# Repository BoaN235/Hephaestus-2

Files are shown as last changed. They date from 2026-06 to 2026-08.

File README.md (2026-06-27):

# Hephaestus-2

magazine_page

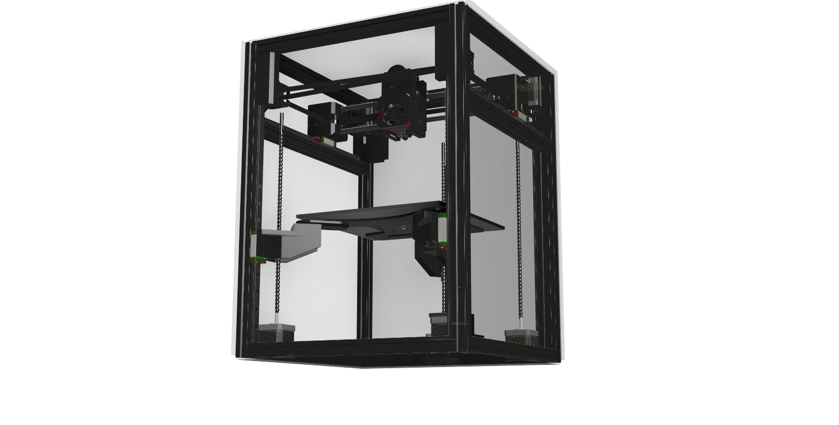
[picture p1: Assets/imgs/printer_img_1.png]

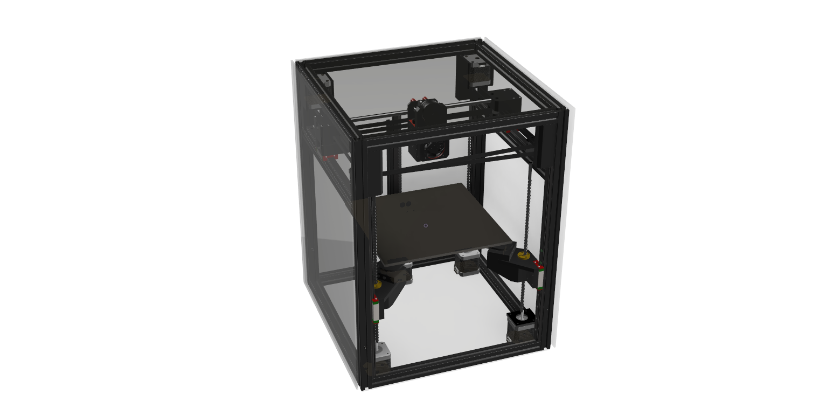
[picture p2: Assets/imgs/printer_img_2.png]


## Goals:
1. 235x235
2. CoreXY movement system
3. Tension control in the belt 
4. Compact small footprint
5. Enclosed
6. Kinematic Bed (The bed will tilt)

## What is it?
Hephaestus-2 is the second version my custom 3D printer. Hephaestus-2 will be a CoreXY printer with a Kinematic Bed that will be enclosed. That sounds like a lot so let me explain what each of those things mean. 

- What is a 3D Printer?

    A 3D Printer is a machine that uses additive manufacturing to create things. A 3D Printer does this by extruding a material and building it up layer by layer. 3D Printers usually they extrude plastics however there is also some other types of Filaments.

- What is a CoreXY motion system?

    a Core XY motion system is a motion system where the X and Y axis are controlled with two motors that work together to manage the X and Y axes. These systems tend to work well in 3D Printers because they allow for fast precision control of a 3D Printer head.

- What is a Kinematic Bed?

    A Kinematic Bed is a 3D Printer bed that tilts using a three point mounting systems. This allows the bed to tilt. The bed tilting allows for the printer to have better first layers and even allow them to change layer angles.

- What is a enclosed 3D Printer?

## Why did I make it?
I want to learn engineering and I was very interested in 3D Printing as its a powerful tool to design your own parts. However I had never used one before so I did a lot of research and wanted to build my own. This brought me to the hack club event [Infill](https://infill.hackclub.com/) and I was able to participate and go to [demo it at RMMRF](https://youtu.be/5G_g6yMLbMs?si=Rk1-EXst3To_MMzO). Recently I wanted to add many improvements however I became very busy so I had to wait a year to resume progress. 

## Should you build your own?
Right now I would not recommend you build your own as currently the firmware is not setup and there will inevitably problems that have to be fixed when I build it. Also I won't be able to release a full build guide until I build it myself so you would be on your own. Everything I say will just be a estimate about the best ways to build it. 

## Wiring Diagram
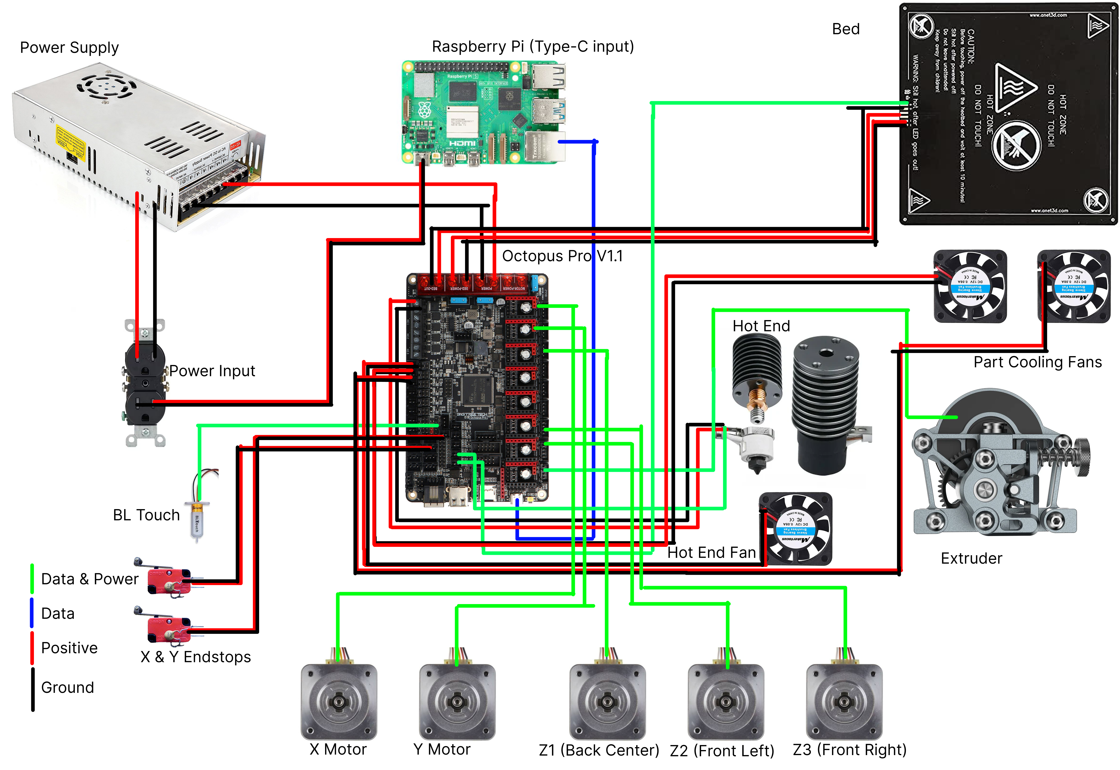
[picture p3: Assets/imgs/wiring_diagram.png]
wiring diagram


## BOM: 
Here is the BOM however I don't need all these parts to build it. the needed_bom.csv file shows the parts I actually need to buy.

| Part Name | Quantity | Units | Unit Cost | Part Cost | Full Price | Part Link | Part Description | Part Number |
|---|---|---|---|---|---|---|---|---|
| Octopus Pro V1.1 | 1 | 1 | $64.99 | $64.99 | $64.99 | https://www.amazon.com/BIGTREETECH-High-Speed-Printing-Raspberry-Operating/dp/B0BM3BFZ35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 | BIGTREETECH Octopus Pro V1.1 H723 32bit Control Board 550MHz Support 8 Axis Stepper Motor Drivers TMC2209 Klipper/Marlin High-Speed/Voltage Printing Support Raspberry-Pi Octprint Operating Systems | US-1020000408 |
| Lead Screws 300mm | 1 | 4 | $3.49 | $13.97 | $13.97 | https://www.amazon.com/QWORK-300mm-Thread-Starts-Printer/dp/B0C2VKKB5D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 | QWORK 4 Pack T8 300mm Lead Screw and Brass Nut (Acme Thread, 4 Starts, 2mm Pitch, 8mm Lead) Used in 3D Printer | QWORK-‎WD30244 |
| MGN12 Linear Rails 350mm | 1 | 4 | $15.51 | $62.02 | $62.02 | https://www.amazon.com/ANWOKIT-Miniature-Sliding-Printer-Machine/dp/B0BS9NQPGZ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 | [4 Pack] MGN12 350mm Linear Sliding Rail Guide with 4pcs MGN12H Linear Bearing Sliding Carriage Block for 3D Printer and CNC Machine | BEVDICNC-‎S2132876GIMX |
| Ball Bearings Ø10mm | 1 | 20 | $0.35 | $6.99 | $6.99 | https://www.amazon.com/uxcell-Bearing-Balls-Stainless-Precision/dp/B07YKLMB5X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 | uxcell 10mm Bearing Balls 304 Stainless Steel G100 Precision Balls 20pcs | uxcell-a19091100ux0316 |
| Aluminum Extrusion 2020 400mm | 1 | 8 | $3.62 | $28.99 | $28.99 | https://www.amazon.com/Seekliny-Aluminum-Extrusion-V-Slotted-Accessories/dp/B0DY7HXV9C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 | 8Pack 2020 Aluminum Extrusion V-Slot 400mm Black Extruded Aluminum Profile 20x20 V-Slotted Framing European Standard Anodized Linear Rail for 3D Printer Accessories Parts | SeekLiny-B0DY7HXV9C |
| Idler Pullys Toothless | 1 | 5 | $1.80 | $8.99 | $8.99 | https://www.amazon.com/WINSINN-Aluminum-Timing-Pulley-Printer/dp/B07CCMQ8T7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 | GT2 Idler Pulley - 20 Toothless, 5mm Bore, for 6mm Width Timing Belt, Aluminum - Ideal for 3D Printers, CNC Machines (5-Pack) | WINSINN-6MMHL20T5N |
| Idler Pullys Toothed | 1 | 5 | $1.80 | $8.99 | $8.99 | https://www.amazon.com/WINSINN-Aluminum-Timing-Pulley-Printer/dp/B07BPGYX3G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 | GT2 Idler Pulley - 20 Teeth, 5mm Bore, for 6mm Width Timing Belt, Aluminum - Ideal for 3D Printers, CNC Machines (5-Pack) | WINSIN-6MMHL20T5T |
| 20x20 Aluminum Extrusions 1220mm | 1 | 10 | $6.74 | $67.39 | $47.41 | https://www.amazon.com/CNCYEAH-Aluminum-Extrusion-European-connectors/dp/B0CCJ7HBX9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 | Its on sale | HFSB5-2020-320 |
| Linear Bearings | 1 | 4 | $9.99 | $9.99 | $9.99 | https://www.amazon.com/HiPicco-Bearings-LM8LUU-Bushing-Machine/dp/B0BR2FJ8JB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 | Linear Ball Bearings, LM8LUU 8mm Bore Longer Linear Motion Bushing Double Side Rubber Sealed Rod Liner Shaft Parts for CNC Machine 3D Printer 4 Pack | HiPicco-H2021122702 |
| Nema Stepper Moter 3PC | 2 | 3 | $8.66 | $51.98 | $51.98 | https://www.amazon.com/STEPPERONLINE-Stepper-Bipolar-42x42x38mm-Connector/dp/B0B38GHRH8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 | STEPPERONLINE Nema 17 Stepper Motor Bipolar 1.5A 42Ncm 42x42x38mm 1.8deg 4 Wires with 1m Cable and Connector (3 Pack) | 3-17HE15-1504S |
| Lead Screw Couplers | 1 | 5 | $2.00 | $9.99 | $9.99 | https://www.amazon.com/AFUNTA-Flexible-Couplings-Compatible-Machines/dp/B07JL1QYLS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 | AFUNTA 5 Pcs Flexible Couplings 5mm to 8mm Compatible with NEMA 17 Stepper Motors, Used in Small CNC Machines & 3D Printer Prusa i3 or ORD Bot with 2 Pcs Allen Wrench | ‎B07JL1QYLS |
| mini fan 2-pack | 1 | 4 | $2.25 | $8.99 | $8.99 | https://www.amazon.com/MakerFocus-Printer-40X40X10mm-Appliances-Replacement/dp/B07CH6YC32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 | 4pcs 3D Printer Fan 12V, 40mm 12 Volt 0.08A DC Mini Quiet Cooling 40 x 40 x10mm with 28cm Cable for 3D Printer, DVR and Other Small Appliances Series Repair Replacement | N/A |
| Sherpa Extruder | 1 | 1 | $36.89 | $36.89 | $36.89 | https://www.amazon.com/Accessories-Lightweight-Extruder-Compatible-Ender3v2/dp/B0CNPG9QB2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 | Upgrade 3D Printer Accessories Parts Lightweight Sherpa Dual Gear Mini Extruder with Motor Compatible with Ender3v2 Pro Cr10 Q5 Qq-S Voro2.4 V0.1 0.2 | N/A |
| Hot Bed | 1 | 1 | $23.99 | $23.99 | $23.99 | https://www.amazon.com/Aluminum-Heated-Upgrade-Printer-220x220mm/dp/B09QWBSD3B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 | Aluminum MK2 MK3 12V Heated Bed Hotbed Upgrade with Hotbed Wire Cable Line for Anet A8 A6 3D Printer, Black 220x220mm | N/A |
| Power Supply | 1 | 1 | $22.99 | $22.99 | $22.99 | https://www.amazon.com/SUPERNIGHT-Switching-Universal-Regulated-Transformer/dp/B01LATMSGS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 | SUPERNIGHT 12V 30A Switching Power Supply, 110-240 Volt AC to DC 360W Universal Regulated Switching Transformer Adapter Driver for 3D Printer, CCTV, Radio, LED Strip Lights,Computer Project | N/A |
| PTFE Tubes | 1 | 1 | $5.99 | $5.99 | $5.99 | https://www.amazon.com/Ultra-Smooth-Teflon-Tubing-Friction-Creality/dp/B0DLV5C1JS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 | Ultra-Smooth PTFE Teflon Tubing 2m, 2.5mm ID × 4mm OD PTFE Tube Fits Direct Drive Extruder 3D Printer For Bambu Lab A1/A1 mini/P1P/P1S/X1C,Creality K1 Series/Ender 3 V3 -Translucent | N/A |
| E3D V6 | 1 | 1 | $13.99 | $13.99 | $13.99 | https://www.amazon.com/Wangdd22-1-75mm-Printer-Extruder-Accessories/dp/B06XBXDJY3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 | E3D V6 Hot End Full Kit 1.75mm 12V Bowden/RepRap 3D Printer Extruder Parts Accessories 0.4mm Nozzle | N/A |
| M3-Screws | 1 | 1 | $8.99 | $8.99 | $8.99 | https://www.amazon.com/800Pcs-Socket-Assortment-Washers-Printing/dp/B0DR92YVL5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 | 800Pcs M3 Screw Kit,Hex Socket Head Cap Screws Assortment with Nuts and Washers 12.9 Grade Alloy Steel Black Zinc Plated Metric Screws,M3 Bolts for 3D Printing | N/A |
| M5-Screws | 1 | 1 | $9.99 | $9.99 | $9.99 | https://www.amazon.com/Bemaka-200PCS-Button-Washers-Assortment/dp/B0CSY7FMQD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 | 200PCS Black M5 Button Head Hex Socket Cap Screws, M5 x 30/35/40/45/50mm Metric Screws Bolts Nuts Washers Assortment Kit, 10.9 Grade Alloy Steel | N/A |
| M3-M5 heated Inserts | 1 | 1 | $15.98 | $15.98 | $15.98 | https://www.amazon.com/Ktehloy-Threaded-Assortment-Printing-Components/dp/B0CLKDPN65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 | 400Pcs Metric Heat Set Insert, M2 M2.5 M3 M4 M5 M6 Female Thread Knurled Nuts Assortment Kit, Brass Threaded Inserts for Plastic and 3D Printing Components (Threaded Inserts Ket) | N/A |
| Bed Carriage | 1 | 1 | $25.99 | $25.99 | $25.99 | https://www.amazon.com/Befenybay-Modular-Carriage-Upgrade-Aluminum/dp/B082ZZ9LSV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 | Modular Y Carriage Plate Upgrade for 2040V Aluminum Profile for Ender3/Ender3 Pro 3D Printer (190mm) | N/A |
| TOTAL | | | | $447.13 | $427.15 | | | |

## Building tips
1. To start to build the printer I would recommend assembling the frame first as this is where everything else gets mounted.
2. Next you should put together the head and put setup the belt system.
3. Add the bed and bed movement systems.

More detail when I build it.

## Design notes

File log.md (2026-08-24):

# log 
## Total Time Estimate 11 hours

## Log #1 Toolhead
**Time: 1 hour**

### Designed 3D Printer Head.
One of the problems I ran into with my old version of my Printer was that the toolhead was very large and it was very fragile. This version should be much stronger and is much smaller than the old version. I was able to compact the fans closer to the center which makes it much smaller. Also I designed a smaller carriage and it has a space to add the BlTouch. The BlTouch will act as a z stop and find the bed mesh so the bed can tilt to counteract it.







## Log #2 Belts
**Time: 2 hours**

### Belt Paths & Bed Movement
The largest problem with my old 3D Printer was the belts. They were the main limiting factor because they caused the printer to skip overtime. I am very chose to create a cad model of the belt system so that I don't make any mistakes when I eventually design it.



After I designed the prototype belt paths I imported those over to the main cad along with mounts for the stepper motors. The prototype path already makes the printer look much better than the previous version.



### Belt Holder Design
The last version had a large problem whenever I assembled it because there was no way to tension the belt it was very hard to put the belts on. However I am changing that by adding a tensioner. There will be a small screw with a nut that you tighten to increase the tension in the belt.



In this second image you can see one of the designs I was working on before I ended up coming up with the tensioner design. This would have had the same problem as my old printer and would have been hard to assemble.



## Log #3 Gantry
**Time: 2 hours**

### Gantry Carriage & Toolhead Belt connection
The first design I came up for my gantry carriage was a tall thin design. I thought that the strength of the plastic would be enough to stop the belt and hold the toolhead. However I later decided to change it.



Here you can see a scraped design for connecting the belts to the toolhead. This wouldn't have worked because to remove the belts you would have had to take apart the toolhead.



I did end up changing the gantry carriage to a shorter design with a stacked top. I did this by moving the aluminum extrusion up to allow me to make the shorter design. The shorter design will be easier to assemble and it will be fairly strong as its pretty much a brick of plastic.




## Log #4 Z-Axis and fixes
**Time: 3 hours**

## Z-axis system
I am creating the Z axis system and it is very complicated because I need to ensure that each of the motors can connect to the bed loosely. I decided that I am going to connect them with a 10mm metal bearing that the bed will sit on top of and this will allow the bed to tilt.





## Tool Head Fixes & Toolhead Belt attachment
I fixed some of the small problems on the toolhead. However the main thing I worked on was the back piece for the belt connecter. My idea is that it screws on to the back of the printer head.




## Bed improvements
I designed the connections of the z-axis to the bed itself. 




The other improvement I added was adding the toolhead carriage which will connect to the belts and linear rods.



## Log #5 Final touches
**Time: 3 hours**

I spent very little time actually working on the printer and instead setting up the github repo along with creating the bom and finding what parts I actually need to buy. Also I am rewriting the log because my original one was very bad. Here is what the printer looks like as of today.




# Build Time!!

## Log #1 Rebuilt the frame after OUTPOST!!! Hours: 1

## Log #2 fixed Toolhead parts and printed them Hours: 2

## Log #3 Put it together with the belts! Hours: 5

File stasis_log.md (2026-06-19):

# Initial work before This event started also explains what I want more for this project
Hephaestus-1v2
title: "Hephaestus-1v2" description: "A Core XY Printer with a z axis tilt" Made by : Boa_N

Total Time: 7 hours

Goals and Requirements
Idk if i wanna do 235x235 or 220x220
CoreXY
Enclosed
Z Tilt bed
Compressed into a small footprint ~360x360x470 mm or ~14.17x14.17x18.5 in
I would like to design a pcb for this project
info
This version was built with the old parts of Hephaestus-1 an broken Ender 3V3 and a few new parts





# log
Feb 21st - Feb 24th Toolhead Work Time: 2.5 hours
Feb 25th - Mar 1st Main Body Overall Design Time 3.5 hours

## Belt Paths & setting up for bed movement
The main thing I worked on was the belt paths for the 3d printer. These will allow the head of the 3d printer to move around in the normal coreXY way.



I also added the parts that will eventually be used for the z-axis kinematic system. Each of the 3 points has a servo moter that will be able to turn a screw. With a three point system it allows the bed to tilt.



## Belt Holder Design W/ Tensinor 
I had multiple different ideas however this is the final one I found that would work the best. It allows for me to put a nut and tension the belt. This will help to make assembly easier and fix a main problem in the original version with problems in the belts.



This shows a design I chose not to move on with because it did not give me the ability to tension it well



## Gantry System & Toolhead Belt connection
I setup the first design of the gantry system. It will allow for the belts to pull the toolhead and gantry. currently it may change in location as I think if I change the belt system it would work better.


I also worked on a connection to the belt system that part will probably be finished last because


## Belt System & Bed
I finished the belt system which will pull the gantry it looks like it isn't connected because I wanted to build it with tolerances in mind. The entire belt system has tolerance built in so I can adjust it to make installation easier.



This is what the printer looks like currently. I think it is looking much better than the original and the newer features such as a kinematic z axis make the printer much more unique.


## Z-axis system
I worked on starting to create the z-axis movement system. this took a while because I had to get the exact measurements of the piece however they are located in the correct locations. Next I want to work on the semi-universal joints to make connect to the center bed area.





## Tool Head Fixes & Toolhead Belt attachment
Today I fixed some of the small problems on the toolhead. However the main thing I worked on was the back piece for the belt connecter. My idea is that it screws on however this will probably change later. For now I think it will work.



## Bed improvements
I designed the bed connections. The Kinematic Z axis will be later on in the future because I need to ensure that the printer works well first.



Other than improvements in the toolhead the printers design is complete. I hope to get started with the build process mid may.



## Kinematic Bed System
I have mainly been working on the bed system



I decided to switch to a four point system because it will improve stability and allow me to use advanced Klipper features. Also it helps me to make the parts the exact same so I just have to print two sets of the same ones.

The bed works with a balls that allow it too tilt.



Most of the time was taken up on the 3 point design however I decided that it wasn't going to work as well as a 4 point design.



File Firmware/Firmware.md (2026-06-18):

# Firmware

This project uses Klipper and has a config file that should be able to be loaded into Klipper and work.

If you don't know what Klipper is it's a software that communicates between a Micro-Controller and a General Purpose Computer to tell the 3D Printer what to do. This is allows for greater precision by telling the Computer to calculate variables and commands while the Micro Controller handles executing commands. 

Check it out on [github](https://github.com/Klipper3d/klipper/)



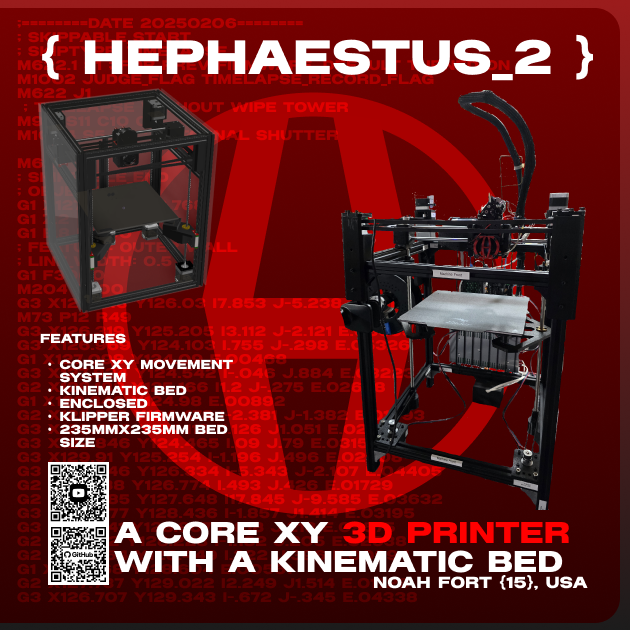
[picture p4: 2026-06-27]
magazine_page.png

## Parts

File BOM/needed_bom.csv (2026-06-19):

Part Name | Quantity | Units | Unit Cost | Total Part Cost | Full Cost | Part Link | Part Description | Description | Part Number
Octopus Pro V1.1 | 1 | 1 | $64.99 | $64.99 | $64.99 | https://www.amazon.com/BIGTREETECH-High-Speed-Printing-Raspberry-Operating/dp/B0BM3BFZ35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 | BIGTREETECH Octopus Pro V1.1 H723 32bit Control Board 550MHz Support 8 Axis Stepper Motor Drivers TMC2209 Klipper/Marlin High-Speed/Voltage Printing Support Raspberry-Pi Octprint Operating Systems | This is the controller for the printer and handles commands from the raspberry pi | US-1020000408
Lead Screws 300mm | 1 | 4 | $3.49 | $13.97 | $13.97 | https://www.amazon.com/QWORK-300mm-Thread-Starts-Printer/dp/B0C2VKKB5D | QWORK 4 Pack T8 300mm Lead Screw and Brass Nut (Acme Thread, 4 Starts, 2mm Pitch, 8mm Lead) Used in 3D Printer | These make the bed axis move up or down depending on the stepper moters. | QWORK-‎WD30244
MGN12 Linear Rails 350mm | 1 | 4 | $15.51 | $62.02 | $62.02 | https://www.amazon.com/ANWOKIT-Miniature-Sliding-Printer-Machine/dp/B0BS9NQPGZ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 | [4 Pack] MGN12 350mm Linear Sliding Rail Guide with 4pcs MGN12H Linear Bearing Sliding Carriage Block for 3D Printer and CNC Machine | These will support movement in each side of the z axis. | BEVDICNC-‎S2132876GIMX
Ball Bearings Ø10mm | 1 | 20 | $0.35 | $6.99 | $6.99 | https://www.amazon.com/uxcell-Bearing-Balls-Stainless-Precision/dp/B07YKLMB5X | uxcell 10mm Bearing Balls 304 Stainless Steel G100 Precision Balls 20pcs | These are the joints that will allow the printers bed to tilt. | uxcell-a19091100ux0316
Aluminum Extrusion 2020 400mm | 1 | 8 | $3.62 | $28.99 | $28.99 | https://www.amazon.com/Seekliny-Aluminum-Extrusion-V-Slotted-Accessories/dp/B0DY7HXV9C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 | 8Pack 2020 Aluminum Extrusion V-Slot 400mm Black Extruded Aluminum Profile 20x20 V-Slotted Framing European Standard Anodized Linear Rail for 3D Printer Accessories Parts | This is for the frame of the 3d printer and will securely hold it in together. | SeekLiny-B0DY7HXV9C
Idler Pullys Toothless | 1 | 5 | $1.80 | $8.99 | $8.99 | https://www.amazon.com/WINSINN-Aluminum-Timing-Pulley-Printer/dp/B07CCMQ8T7 | GT2 Idler Pulley - 20 Toothless, 5mm Bore, for 6mm Width Timing Belt, Aluminum - Ideal for 3D Printers, CNC Machines (5-Pack) | These allow the back part of the belt to move smoothly in the gantry system | WINSINN-6MMHL20T5N
Idler Pullys Toothed | 1 | 5 | $1.80 | $8.99 | $8.99 | https://www.amazon.com/WINSINN-Aluminum-Timing-Pulley-Printer/dp/B07BPGYX3G | GT2 Idler Pulley - 20 Teeth, 5mm Bore, for 6mm Width Timing Belt, Aluminum - Ideal for 3D Printers, CNC Machines (5-Pack) | these allow the gantry of the 3d printer to move and interface with the belts | WINSIN-6MMHL20T5T
20x20 Aluminum Extrusions 1220mm | 1 | 10 | $6.74 | $67.39 | $47.41 | https://www.amazon.com/CNCYEAH-Aluminum-Extrusion-European-connectors/dp/B0CCJ7HBX9 | Its on sale | N/A | HFSB5-2020-320
Linear Bearings | 1 | 4 | $9.99 | $9.99 | $9.99 | https://www.amazon.com/HiPicco-Bearings-LM8LUU-Bushing-Machine/dp/B0BR2FJ8JB?xpid=pMg_yEY_IuUxr | Linear Ball Bearings, LM8LUU 8mm Bore Longer Linear Motion Bushing Double Side Rubber Sealed Rod Liner Shaft Parts for CNC Machine 3D Printer 4 Pack | N/A | HiPicco-H2021122702
Nema Stepper Moter 3PC | 1 | 3 | $8.66 | $25.99 | $25.99 | https://www.amazon.com/STEPPERONLINE-Stepper-Bipolar-42x42x38mm-Connector/dp/B0B38GHRH8 | STEPPERONLINE Nema 17 Stepper Motor Bipolar 1.5A 42Ncm 42x42x38mm 1.8deg 4 Wires with 1m Cable and Connector (3 Pack) | N/A | 3-17HE15-1504S
Lead Screw Couplers | 1 | 5 | $2.00 | $9.99 | $9.99 | https://www.amazon.com/AFUNTA-Flexible-Couplings-Compatible-Machines/dp/B07JL1QYLS | AFUNTA 5 Pcs Flexible Couplings 5mm to 8mm Compatible with NEMA 17 Stepper Motors, Used in Small CNC Machines & 3D Printer Prusa i3 or ORD Bot with 2 Pcs Allen Wrench | N/A | ‎B07JL1QYLS
TOTAL |  |  |  | $308.30 | $288.32

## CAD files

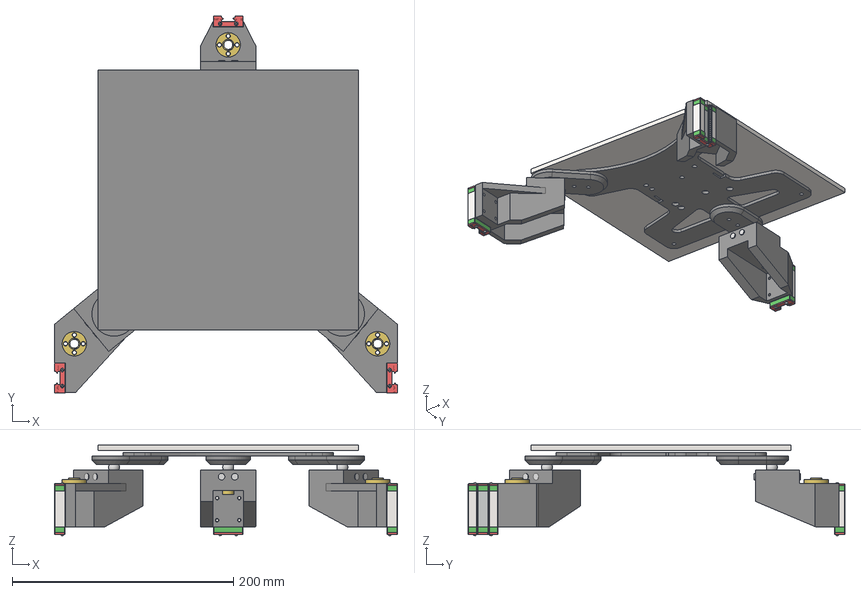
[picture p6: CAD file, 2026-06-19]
CAD/Parts/Bed.stp
310.0 x 340.6 x 81.9 mm
LeadScrew Nut 8mm x 2mmPitch x 2
LeadScrew Nut 8mm x 2mmPitch_1
Bed_Carriage

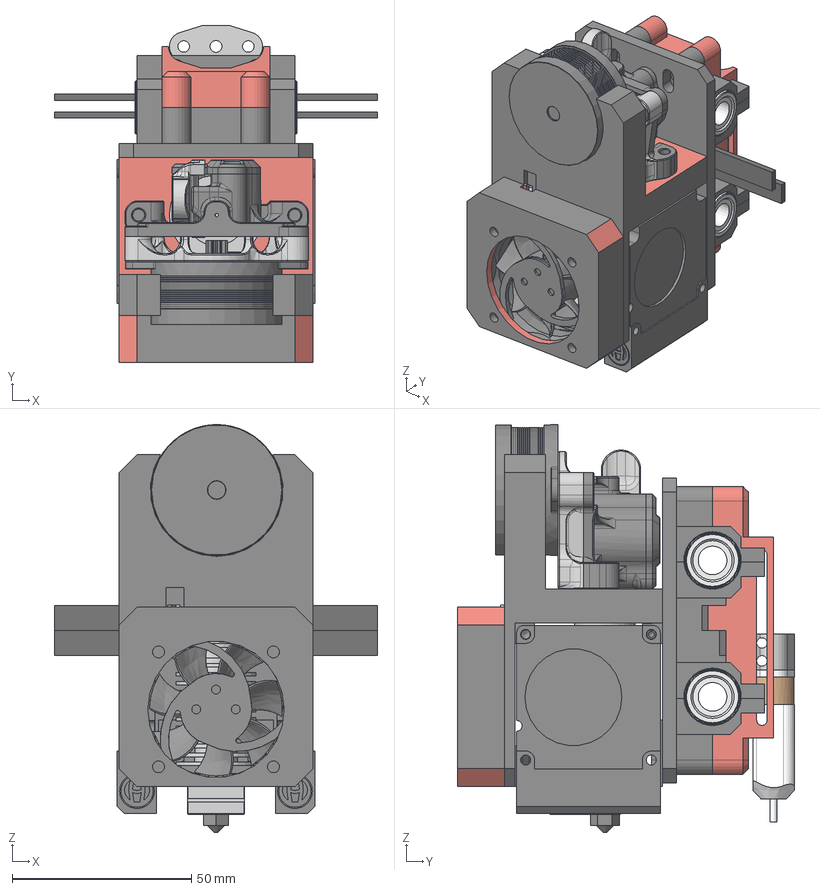
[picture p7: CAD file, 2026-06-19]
CAD/Parts/Toolhead.stp
90.0 x 93.8 x 113.7 mm
linear_bearing x 2
BL-touch

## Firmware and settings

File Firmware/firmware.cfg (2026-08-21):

# This file is an example config file for corexy (and also h-bot)
# style printers. One may copy and edit this file to configure a new
# corexy printer.

# DO NOT COPY THIS FILE WITHOUT CAREFULLY READING AND UPDATING IT
# FIRST. Incorrectly configured parameters may cause damage.

# See docs/Config_Reference.md for a description of parameters.


[board_pins octopus_pro_h723_tmc2209]
aliases:

  # X
  x_step_pin=PF13,
  x_dir_pin=PF12,
  x_enable_pin=PF14,
  x_endstop_pin=PG6,

  # Y
  y_step_pin=PG0,
  y_dir_pin=PG1,
  y_enable_pin=PF15,
  y_endstop_pin=PG9,

  # Z0
  z0_step_pin=PC13,
  z0_dir_pin=PF0,
  z0_enable_pin=PF1,

  # Z1
  z1_step_pin=PE2,
  z1_dir_pin=PE3,
  z1_enable_pin=PD4,

  # Z2
  z2_step_pin=PE6,
  z2_dir_pin=PA14,
  z2_enable_pin=PE0,

  # Extruder
  e_step_pin=PF11,
  e_dir_pin=PG3,
  e_enable_pin=PG5,

  # Extruder heater
  e_heater_pin=PA2,
  e_sensor_pin=PF4,

  # Bed heater
  heater_bed_heating_pin=PA1,
  heater_bed_sensor_pin=PF3,

  # Part cooling fan
  fan_part_cooling_pin=PA8,


# ============================================================
# X AXIS
# ============================================================

[stepper_x]
step_pin: PF13
dir_pin: PF12
enable_pin: !PF14

microsteps: 16
rotation_distance: 40

endstop_pin: ^PG6
position_endstop: 0
position_max: 200
homing_speed: 50


# ============================================================
# Y AXIS
# ============================================================

[stepper_y]
step_pin: PG0
dir_pin: PG1
enable_pin: !PF15

microsteps: 16
rotation_distance: 40

# Original probe-based homing:
# endstop_pin: probe:z_virtual_endstop

# Use the physical Y endstop from the board pin aliases
endstop_pin: ^PG9

position_min: 0
position_max: 200
homing_speed: 50


# ============================================================
# Z AXIS
# ============================================================
#
# THREE Z MOTORS
#
# All three motors move together whenever Klipper commands Z.
#
# Z0 = PC13 / PF0 / PF1
# Z1 = PE2  / PE3 / PD4
# Z2 = PE6  / PA14 / PE0
#
# ============================================================


# ============================================================
# Z MOTOR 1
# ============================================================

[stepper_z]
step_pin: PC13
dir_pin: PF0
enable_pin: !PF1

microsteps: 16
rotation_distance: 8

endstop_pin: ^PD3
position_endstop: 0.5
position_max: 200


# ============================================================
# Z MOTOR 2
# ============================================================

[stepper_z1]
step_pin: PE2
dir_pin: PE3
enable_pin: !PD4

microsteps: 16
rotation_distance: 8


# ============================================================
# Z MOTOR 3
# ============================================================

[stepper_z2]
step_pin: PE6
dir_pin: PA14
enable_pin: !PE0

microsteps: 16
rotation_distance: 8


# ============================================================
# OLD SINGLE Z MOTOR CONFIG
# KEPT FOR REFERENCE
# ============================================================

# [stepper_z]
# step_pin: PL3
# dir_pin: PL1
# enable_pin: !PK0
# microsteps: 16
# rotation_distance: 8
# endstop_pin: ^PD3
# position_endstop: 0.5
# position_max: 200


# ============================================================
# EXTRUDER
# ============================================================

[extruder]
step_pin: PA4
dir_pin: PA6
enable_pin: !PA2

microsteps: 16
rotation_distance: 33.500

nozzle_diameter: 0.400
filament_diameter: 1.750

heater_pin: PB4

sensor_type: ATC Semitec 104GT-2
sensor_pin: PK5

control: pid
pid_Kp: 22.2
pid_Ki: 1.08
pid_Kd: 114

min_temp: 0
max_temp: 250


# ============================================================
# BED HEATER
# ============================================================

[heater_bed]
heater_pin: PH5

sensor_type: EPCOS 100K B57560G104F
sensor_pin: PK6

control: watermark

min_temp: 0
max_temp: 130


# ============================================================
# FAN
# ============================================================

[fan]
pin: PH6


# ============================================================
# MCU
# ============================================================

[mcu]
serial: /dev/ttyACM0


# ============================================================
# PRINTER
# ============================================================

[printer]
kinematics: corexy

max_velocity: 300
max_accel: 3000

max_z_velocity: 25
max_z_accel: 30


# ============================================================
# BLTOUCH
# DISABLED
#
# Kept here so you can easily enable it later.
# ============================================================

# [bltouch]
# sensor_pin: ^PB5
# control_pin: PB6
#
# # Offsets
# x_offset: -25
# y_offset: -5
# z_offset: 0
#
# speed: 5
# samples: 2
# sample_retract_dist: 3.0


# ============================================================
# BED LEVELING
# DISABLED
#
# Old code preserved.
# ============================================================


# ------------------------------------------------------------
# SAFE Z HOME
# ------------------------------------------------------------

# [safe_z_home]
# home_xy_position: 100,100
# speed: 50
# z_hop: 10
# z_hop_speed: 5


# ------------------------------------------------------------
# SCREWS TILT ADJUST
# ------------------------------------------------------------

# [screws_tilt_adjust]
# screw1:
# screw1_name: front_left
#
# screw2:
# screw2_name: front_right
#
# screw3:
# screw3_name: back_center
#
# horizontal_move_z: 10
# speed: 50
# screw_thread: CW-M3


# ------------------------------------------------------------
# Z TILT
# ------------------------------------------------------------

# [z_tilt]
#
# z_positions:
#     # X,Y of Z1 Motor
#     # X,Y of Z2 Motor
#     # X,Y of Z3 Motor
#
# points:
#     # X,Y probe point for Z1
#     # X,Y probe point for Z2
#     # X,Y probe point for Z3
#
# speed: 50
# horizontal_move_z: 10
# retry_tolerance: 0.05


# ------------------------------------------------------------
# BED MESH
# ------------------------------------------------------------

# [bed_mesh]
# speed: 120
# horizontal_move_z: 5
# mesh_min: 10,10
# mesh_max: 190,190
# probe_count: 5,5
# algorithm: bicubic
# fade_start: 1.0
# fade_end: 10.0


# ============================================================
# PRINT START
# ============================================================

[gcode_macro PRINT_START]
description: G-code to run at the start of a print

gcode:
    G28 ; Home all axes

    # Bed leveling disabled for now
    # Z_TILT_ADJUST
    # BED_MESH_CALIBRATE

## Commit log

2026-06-10 added BOM
2026-06-18 fixed readme
    [bom.csv, firmware.cfg]
2026-06-19 added bom
    [bom.csv]
2026-06-19 updated BOM and added needed_bom
    [needed_bom.csv]
2026-06-19 Add BL Touch image and update log entries
    Added an image of the BL Touch and updated the log with new belt paths and CAD design details.
2026-06-19 added cad parts
    [Bed.stp, Toolhead.stp]
2026-06-19 updated bom
    [bom.csv, needed_bom.csv]
2026-06-19 updated bom in readme
2026-06-29 Add board pin configuration for octopus_pro_h723
    [firmware.cfg]
2026-08-21 Disable bed tilt adjust and mesh calibration in config
    Comment out bed tilt adjustment and mesh calibration commands.
    [firmware.cfg]
2026-08-21 Refactor firmware configuration and update pin mappings
    Refactor firmware configuration for clarity and organization. Updated stepper and extruder pin configurations, and commented out unused features for future reference.
    [firmware.cfg]
2026-08-21 Refactor firmware configuration for stepper motors
    Removed unused stepper motor configurations and updated pin assignments.
    [firmware.cfg]
2026-08-24 Update log.md with build time entries
    Added build time logs for printer assembly.
